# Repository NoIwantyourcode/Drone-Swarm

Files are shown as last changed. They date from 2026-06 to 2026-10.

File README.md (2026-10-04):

# Drone Swarm

This is a group of 2 drones which are autonoumously controlled by a ground controller to fly in specific patterns, the drone swarm will have 2 drones (this is expandable) and a ground controller, They ground controller will supply instructions to the drone on how to fly and where to fly, The drones will you use their Accelerometers, Gyroscopes and magnetometers to carry out these instructions and fly in a pattern.

# How does it work?

The drones are individually controlled by an onboard flight controller, Each flight controller is connected to the ESP32-S3 ground station which supplies commands to the drones for them to perform it. The ground station recieves input data on the drones location, height and distance from each other from 2 phones, one under and one below which track the the drones. this allows the ground station to have accurate locations for the drones and direct them individually!

The ground station is currently a bare ESP32-S3 DevBoard which is connected to my computer, It features nothing special but it does connect to both drones in a shared connection to supply commands to them. The commands have id's so so the both drones will not follow the same command. There is no case to increase connection strength as the connection won't be blocked by the plastic

# How is it powered

The ground station is connected to my computer and that how it recieves power, The dones have an onboard Lithium-Ion battery at 3.7v to power them for roughly 4 -5 minutes of flght time!

# Why I made this?

I made this as it links to my passion in aviation and I think it is a great way to get started with autonomous flight!

# Connection diagram!

Blank diagram

1. Dotted lines represent Non-physical connections (Bluetooth, wifi, ESP-NOW)
2. Solid lines represent physical connections (cables)

# Schematics


# PCB


# PCB rendered



# Drone frame


# Assembled view


# Fully assembled picture


# Demo link!

Heres the link to a demo video: [https://youtube.com/shorts/X6EJljXOPJc?feature=share](https://youtube.com/shorts/X6EJljXOPJc?feature=share)

# Note for reviewer
The PCB in my assembled view doesn't contain any 3D files for the components as freeCAD would not let me export the components it gathered from my raw PCB file.
The board is also 4 layers and has components on both sides

Lapse also wasn't working for a big part of the design so I wasn't really a record a ton. I only got the first ~1h20mins

Using JLCPCB to 3D print my drone frame as it is in ABS, If I can't use JLC3DP I'll try to find someone through printing legion

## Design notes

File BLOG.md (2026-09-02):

# Blog

# What went wrong?

On my way back from outpost, My baggage was mishandled causing damage to my drone rendering it in an unoperable condition, I sadly do not have pictures of said drone but I was able to fix the drone and get it back to a semi working state, however due to me being stupid, I ordered the wrong motors which weren't powerful enough at 3.7v and outputted 18,000rpm less, This is my mistake as I ordered the wrong the motors and this led to the drone not being powerful enough to lift off, while I have ordered new motors to see if I can get the drone to fly. I don't think I will get them by Sept 30th and even if I do, I won't be able to make the drone in time

# What can I do to fix it?

I used my grant to order new motors which are more efficient and output a higher power at 3.7v and am waiting for them, However I don't think they will arrive on time and even if they do I won't be able to get the drone to work on time so I will be submitting the drone for review now with some previews videos of the drone flying

# What can I do to prevent it from happening again?

When ordering repair parts, double check the specification of the motors you are buying and don't buy any which don't meet the specification or don't have a specification at all

# Current picture of the drone with the wrong motors:


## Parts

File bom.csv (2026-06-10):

Slave Drone |  | Total Price: ~196 | 210
Component | Value | Product link | Qty | Total Price ($) | Notes
Capacitor | 1uF | https://jlcpcb.com/partdetail/53938-CL05A105KA5NQNC/C52923 | 20 | 0.106
Capacitor | 10uF | https://jlcpcb.com/partdetail/20411-CL10A106KP8NNNC/C19702 | 40 | 0.592
Diode | SS14 | https://jlcpcb.com/partdetail/MDD_Microdiode_Semiconductor-SS14/C2480 | 18 | 0.3024
Diode | MBRA340 | https://jlcpcb.com/partdetail/FUXINSEMI-MBRA340T3GFS/C5563736 | 10 | 0.796
USB-C | USB_C_Receptacle_USB2.0_16P | https://jlcpcb.com/partdetail/HCTL-HC_TYPE_C_16P01A/C2894897 | 2 | 0.1972
MOSFET | SI2302-TP | https://jlcpcb.com/partdetail/79111-SI2302TP/C77977 | 12 | 0.5268
Resistor | 10K | https://jlcpcb.com/partdetail/26487-0402WGF1002TCE/C25744 | 24 | 0.0312
Resistor | 4.7K | https://jlcpcb.com/partdetail/26643-0402WGF4701TCE/C25900 | 20 | 0.02
Resistor | 100 | https://jlcpcb.com/partdetail/25819-0402WGF1000TCE/C25076 | 20 | 0.02
Resistor | 20K | https://jlcpcb.com/partdetail/26508-0402WGF2002TCE/C25765 | 20 | 0.02
Resistor | 5.1K | https://jlcpcb.com/partdetail/26648-0402WGF5101TCE/C25905 | 20 | 0.018
IMU | MPU6500 | https://jlcpcb.com/partdetail/TDKInvenSense-MPU6500/C50278 | 2 | 9.0042
ESP32-S3 | ESP32-S3-MINI-1 | https://jlcpcb.com/partdetail/EspressifSystems-ESP32_S3_MINI_1N8/C2913206 | 2 | 9.3612
Voltage Regulator | AP2112K-3.3 | https://jlcpcb.com/partdetail/TECHPUBLIC-AP2112K_33TRG1/C23380830 | 5 | 0.542
Magnetometer | QMC5883P | https://jlcpcb.com/partdetail/QST-QMC5883P/C2847467 | 2 | 3.05 | Changed to P instead of L due to part shortages || Board changed || Same footprint
1x02 pin header | Conn_01x02 | https://www.lcsc.com/product-detail/C42431804.html?s_z=n_q_l_1x02 | 1 | 0.45 | Self assembled || Comes in 20 pins
SMD Push button | SW_Push | https://jlcpcb.com/partdetail/ALPSALPINE-SKRKAHE020/C202388 | 2 | 0.87
CW Motor |  | https://www.aliexpress.com/item/1005006132824490.html?curPageLogUid=64V8cZ9sQfzZ | 4 | 8.13
CCW Motor |  | https://www.aliexpress.com/item/1005006132824490.html?curPageLogUid=64V8cZ9sQfzZ | 4 | 8.24
Propellers |  | https://www.aliexpress.com/item/1005010272672023.html?curPageLogUid=zWIs6ZE8swP7 | 2 | 5
Battery |  | https://www.aliexpress.com/item/1005008217717191.html?curPageLogUid=63gMUGmoaHrD | 2 | 10
Drone Frame |  | https://jlc3dp.com/?spm=Jlc3dp.Homepage.1001 | 2 | 11 | To be printed in ABS-ESD, strong and durable, printed by JLC3DP and will be bundled with the PCB to save money for shipping if possible
 |  |  | Total Parts price | 42.277
 |  |  | Total Price (PCBA fees incl) | 165.58
 |  |  | Total pric with shipping | 184.13
Ground Station
Component | Value | Product link | Qty | Total Price ($) | Notes
ESP32-S3 |  | https://www.aliexpress.com/item/1005011858962686.html?src=google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 | 1 | 12.5 | Communicates to all the drones simoultaneously
3D print case |  |  |  | 0
 |  |  | Total Price of all components: | ~210

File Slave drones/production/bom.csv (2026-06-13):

Designator | Footprint | Quantity | Value | LCSC Part #
C1 | 0402 | 1 | 1uF
C2, C3 | 0603 | 2 | 10uF
D1, D2, D3, D4 | D_SMA | 4 | SS14
D5, D6 | D_SMA | 2 | MBRA340
J1, J2, J3, J4, J6 | PinHeader_1x02_P2.54mm_Vertical | 5 | Conn_01x02
J5 | USB_C_Receptacle_HCTL_HC-TYPE-C-16P-01A | 1 | USB_C_Receptacle_USB2.0_16P
MOSFET1, MOSFET2, MOSFET3, MOSFET4 | SOT-23_MCC | 4 | SI2302-TP
R1, R14, R2, R3, R4, R7, R8 | 0402 | 7 | 10K
R10, R11, R12, R9 | 0402 | 4 | 100
R13 | 0402 | 1 | 20K
R16, R17 | 0402 | 2 | 5.1K
R5, R6 | 0402 | 2 | 4.7K
SW1, SW2 | SW_Push_SPST_NO_Alps_SKRK | 2 | SW_Push
U1 | InvenSense_QFN-24_3x3mm_P0.4mm | 1 | MPU6500 | C50278
U2 | QMC5883L_QST | 1 | QMC5883L | C976032
U3 | XCVR_ESP32-S3-MINI-1-N8 | 1 | ESP32-S3-MINI-1
U4 | SOT-23-5 | 1 | AP2112K-3.3

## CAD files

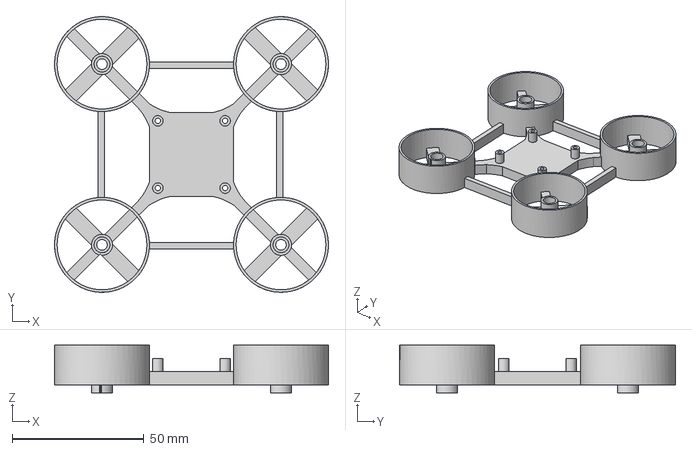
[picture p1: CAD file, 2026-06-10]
Slave drones/Drone frame/drone case.step
103.8 x 104.5 x 18.0 mm

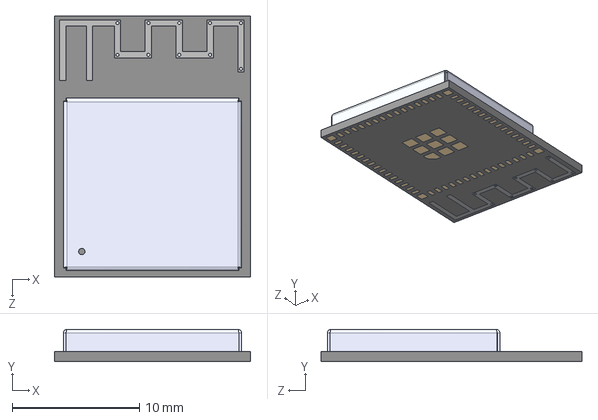
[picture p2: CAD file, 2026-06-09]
Slave drones/ESP32-S3-MINI-1-N8/ESP32-S3-MINI-1-N8.step
15.4 x 2.55 x 20.5 mm

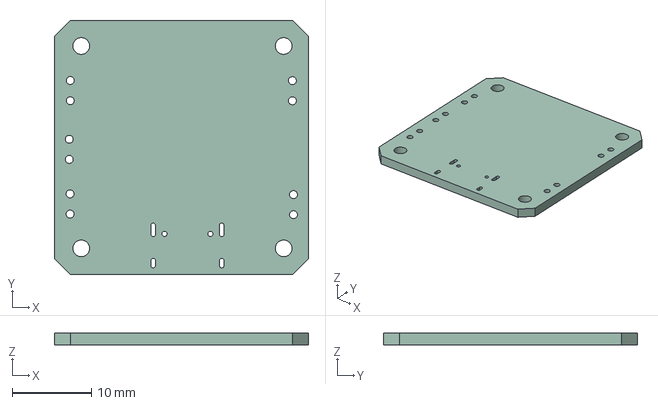
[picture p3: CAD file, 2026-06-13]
Slave drones/pcbmodel.step
32.0 x 32.0 x 1.51 mm

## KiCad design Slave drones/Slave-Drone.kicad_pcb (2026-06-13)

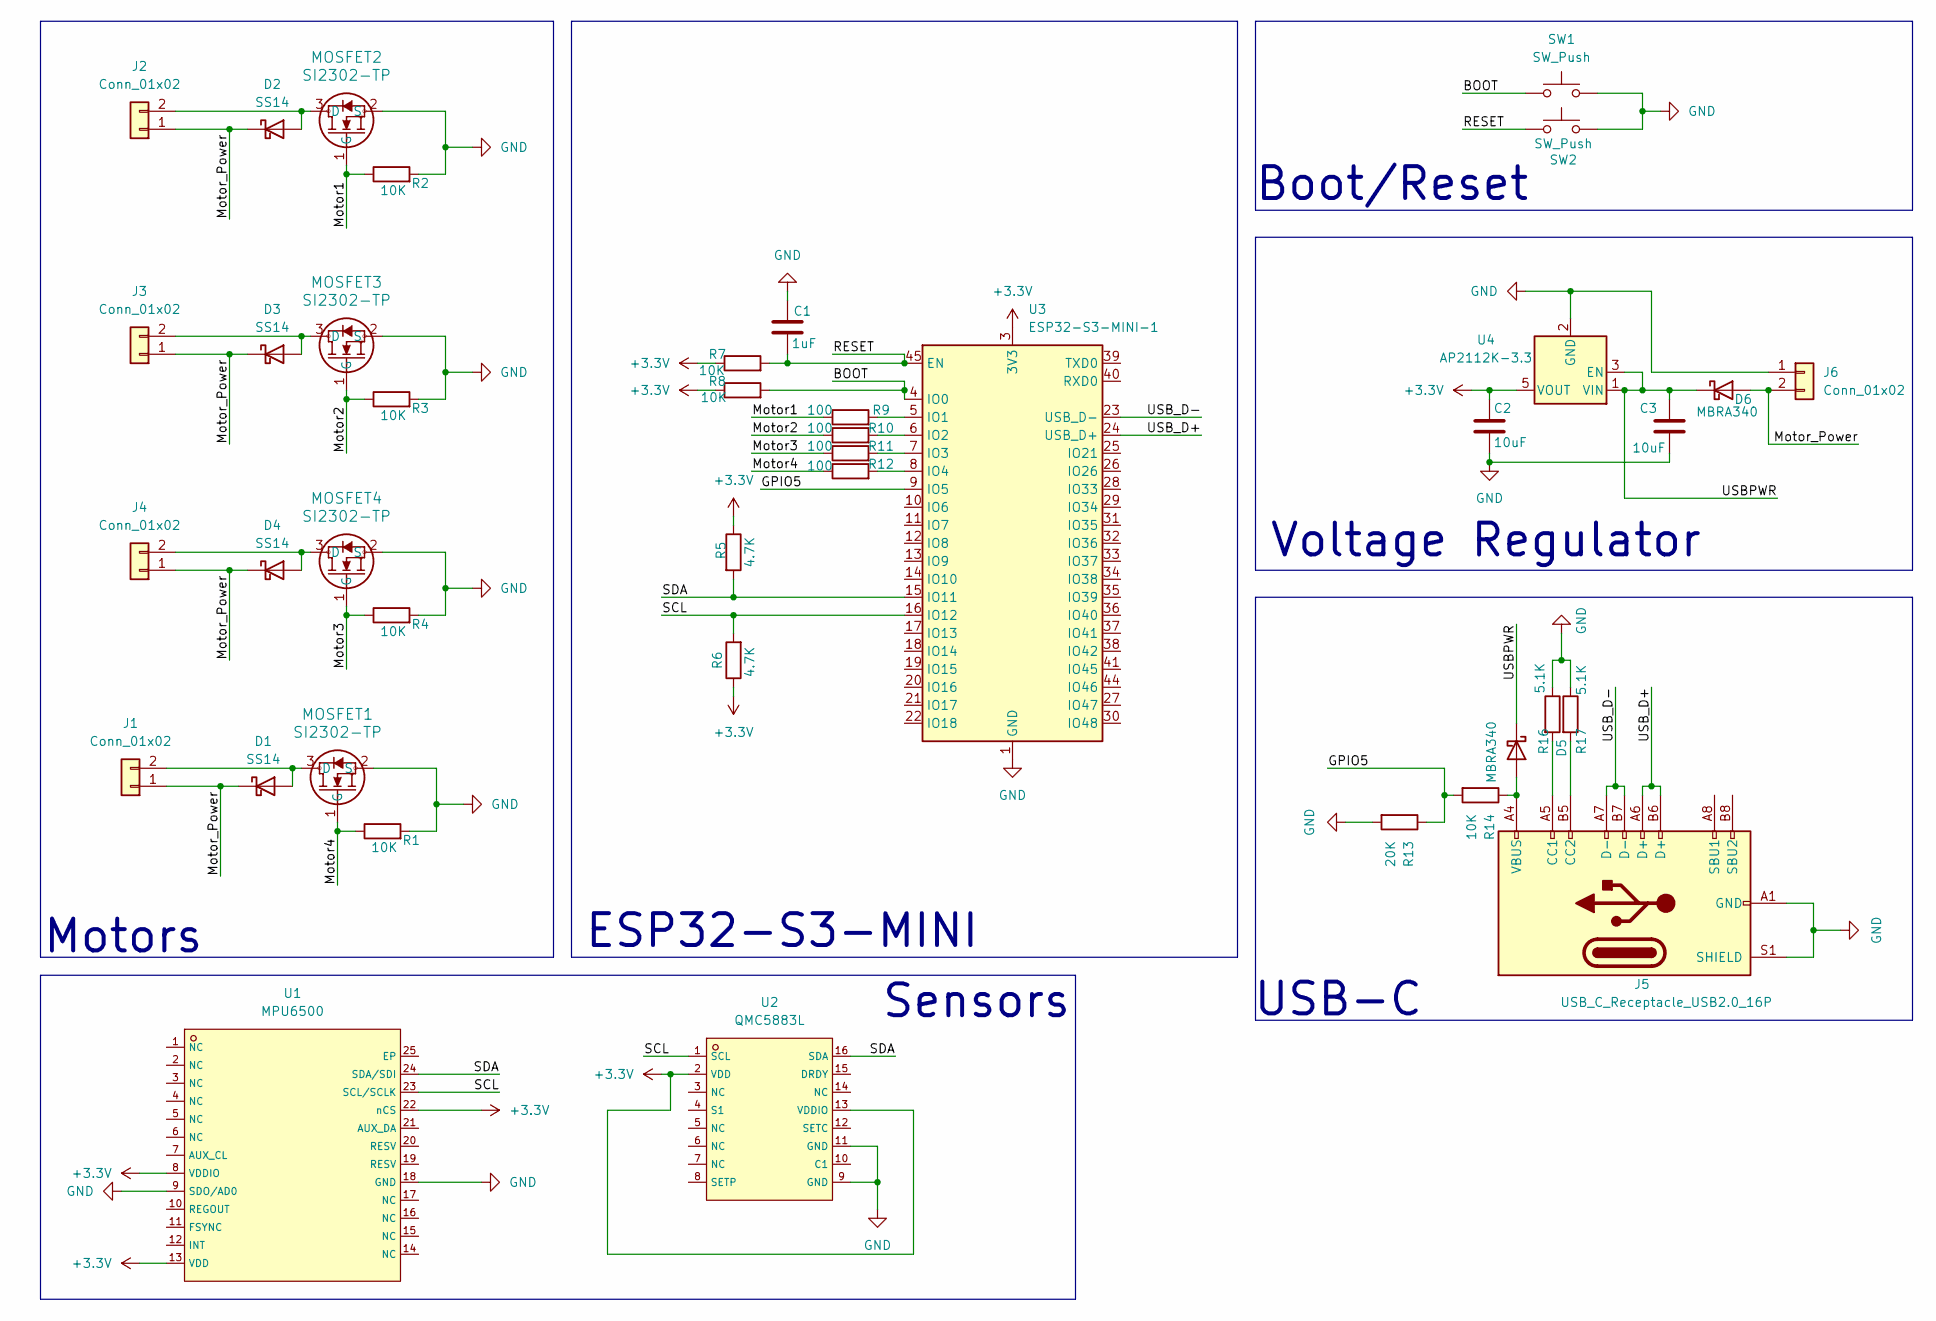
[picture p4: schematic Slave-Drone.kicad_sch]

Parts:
C1: 1uF; C_0402_1005Metric
C2, C3: 10uF; C_0603_1608Metric
D1, D2, D3, D4: SS14; D_SMA
D5, D6: MBRA340; D_SMA
J1, J2, J3, J4, J6: Conn_01x02; PinHeader_1x02_P2.54mm_Vertical
J5: USB_C_Receptacle_USB2.0_16P; USB_C_Receptacle_HCTL_HC-TYPE-C-16P-01A
MOSFET1, MOSFET2, MOSFET3, MOSFET4: SI2302-TP; SOT-23_MCC
R1, R2, R3, R4, R7, R8: 10K; R_0402_1005Metric
R5, R6: 4.7K; R_0402_1005Metric
R9, R10, R11, R12: 100; R_0402_1005Metric
R13: 20K; R_0402_1005Metric_Pad0.72x0.64mm_HandSolder
R14: 10K; R_0402_1005Metric_Pad0.72x0.64mm_HandSolder
R16, R17: 5.1K; R_0402_1005Metric
SW1, SW2: SW_Push; SW_Push_SPST_NO_Alps_SKRK
U1: MPU6500; InvenSense_QFN-24_3x3mm_P0.4mm; LCSC C50278
U2: QMC5883L; QMC5883L_QST; LCSC C976032
U3: ESP32-S3-MINI-1; XCVR_ESP32-S3-MINI-1-N8
U4: AP2112K-3.3; SOT-23-5

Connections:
+3.3V: C2.1, R5.1, R6.1, R7.1, R8.1, U1.8 (VDDIO), U1.13 (VDD), U1.22 (nCS), U2.2 (VDD), U2.13 (VDDIO), U3.3 (3V3), U4.5 (VOUT)
/BOOT: R8.2, SW1.1, U3.4 (IO0)
/GPIO5: R13.1, R14.2, U3.9 (IO5)
/Motor1: MOSFET2.1 (G), R2.1, R9.1
/Motor2: MOSFET3.1 (G), R3.1, R10.1
/Motor3: MOSFET4.1 (G), R4.1, R11.1
/Motor4: MOSFET1.1 (G), R1.1, R12.1
/Motor_Power: D1.1 (K), D2.1 (K), D3.1 (K), D4.1 (K), D6.2 (A), J1.1, J2.1, J3.1, J4.1, J6.2
/RESET: C1.2, R7.2, SW2.1, U3.45 (EN)
/SCL: R6.2, U1.23 (SCL/SCLK), U2.1 (SCL), U3.16 (IO12)
/SDA: R5.2, U1.24 (SDA/SDI), U2.16 (SDA), U3.15 (IO11)
/USBPWR: C3.1, D5.1 (K), D6.1 (K), U4.1 (VIN), U4.3 (EN)
/USB_D+: J5.A6 (D+), J5.B6 (D+), U3.24 (USB_D+)
/USB_D-: J5.A7 (D-), J5.B7 (D-), U3.23 (USB_D-)
GND: C1.1, C2.2, C3.2, J5.A1 (GND), J5.A12 (GND), J5.B1 (GND), J5.B12 (GND), J5.S1 (SHIELD), J6.1, MOSFET1.2 (S), MOSFET2.2 (S), MOSFET3.2 (S), MOSFET4.2 (S), R1.2, R2.2, R3.2, R4.2, R13.2, R16.1, R17.1, SW1.2, SW2.2, U1.9 (SDO/AD0), U1.18 (GND), U2.9 (GND), U2.11 (GND), U3.1 (GND), U3.2 (GND), U3.42 (GND), U3.43 (GND), U3.46 (GND), U3.47 (GND), U3.48 (GND), U3.49 (GND), U3.50 (GND), U3.51 (GND), U3.52 (GND), U3.53 (GND), U3.54 (GND), U3.55 (GND), U3.56 (GND), U3.57 (GND), U3.58 (GND), U3.59 (GND), U3.60 (GND), U3.61 (GND), U3.62 (GND), U3.63 (GND), U3.64 (GND), U3.65 (GND), U4.2 (GND)
unnamed: D1.2 (A), J1.2, MOSFET1.3 (D)
unnamed: D2.2 (A), J2.2, MOSFET2.3 (D)
unnamed: D3.2 (A), J3.2, MOSFET3.3 (D)
unnamed: D4.2 (A), J4.2, MOSFET4.3 (D)
unnamed: D5.2 (A), J5.A4 (VBUS), J5.A9 (VBUS), J5.B4 (VBUS), J5.B9 (VBUS), R14.1
unnamed: J5.A5 (CC1), R16.2
unnamed: J5.B5 (CC2), R17.2
unnamed: R9.2, U3.5 (IO1)
unnamed: R10.2, U3.6 (IO2)
unnamed: R11.2, U3.7 (IO3)
unnamed: R12.2, U3.8 (IO4)

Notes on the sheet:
USB-C
ESP32-S3-MINI
Voltage Regulator
Sensors
Motors
Boot/Reset

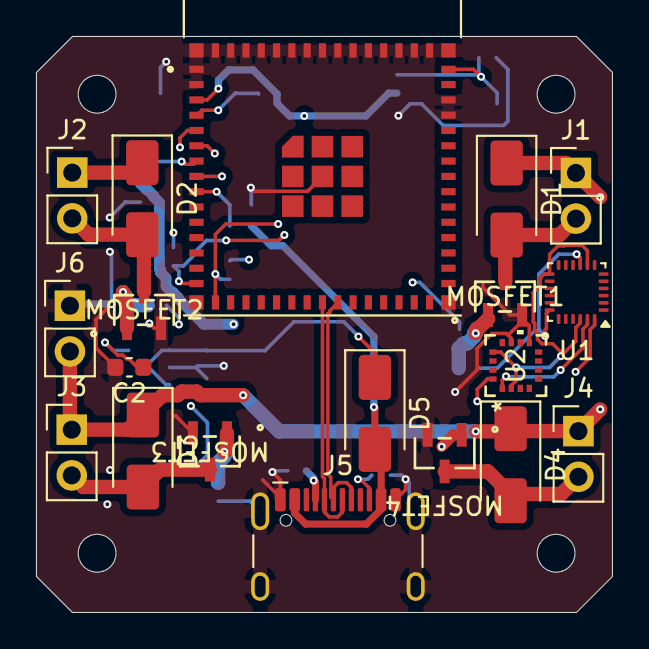
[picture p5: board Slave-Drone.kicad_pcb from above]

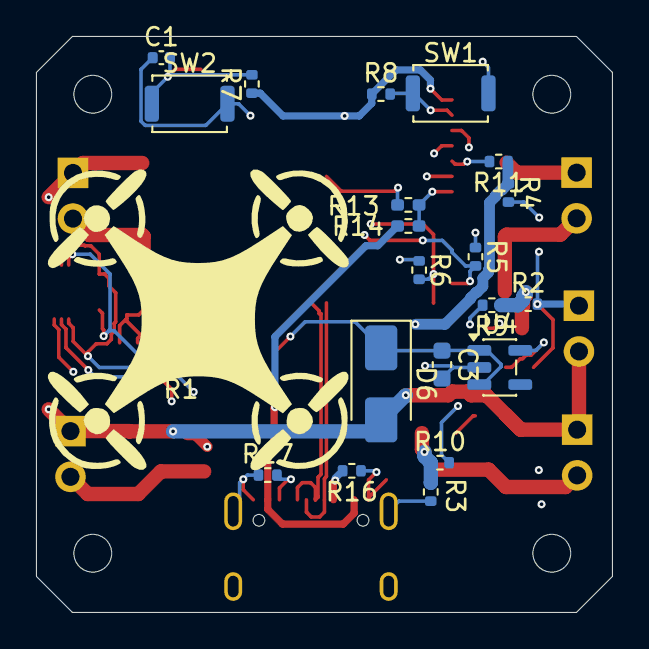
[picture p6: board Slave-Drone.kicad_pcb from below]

Board: 4 copper layers, 32.0 x 32.0 mm, 45 parts (26 on the bottom side), 26 nets.

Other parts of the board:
M1, M2, M3, M4: MountingHole_2.1mm

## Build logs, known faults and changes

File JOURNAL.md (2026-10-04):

**Total time: 70.5 hours**

# June 7th 2026 - I completed the schematics: 3 hours

I completed the schematics for the slave drones which will be controlled by the Ground station, I have decided to use an ESP32 as it is easy to use and already boasts powerful wifi/bluetooth, I have also added 2 sensors, the QMC5883P which is a magnetometer will help the drone saty aligned and the MPU6500 is an Accelerometer + Gyroscope IMU which will help the drone sense its position, I plan to use these to make the drones fly in simple patterns

Picture:


# June 7th 2026 - Routed the PCB: 3 hours

I completely routed the PCB to fit in a board 32mm by 32mm, This will allow it to fit into many widely availible whoop drone frames, The 2mm screw holes are also placed in a 25.5mm by 25.5mm grid which will allow them to screw into any existing whoop drone frame, I have also placed components on both sides of the PCB as it allows me to make it small and light which is very important in order for me be able to fly these drones without having to deal with legal issues.

Picture:


# June 8th 2026 - Made the case - 2 hours

I made the PCB case today as I realised that with the way I mounted the ESP32 I wouldn't be able to mount it at a 45 degree angle, here is a pciture of the case, It has a main 32mmx32mm platform for the flight controller and then 4 arms + propeller guards for the motors

Pictures:



# June 9th 2026 - Fixing the PCB + firmware - 3.5 hours

When I tried to export the board as step file, KiCAD gave me the error code 3, failed to load board, I went down a massive rabbit whole of trying fix it where I thought that something was off with my footprints, when I didn't find anything there I checked to see it the 3D viewer still works and it did, I tried various combinations to get the thing to work but they all failed eventually I even attempted to re-route the whole board but failed as it gave me the same error (even though I made a new file). I also deleted and reinstalled KiCAD thinking that was the problem but that didn't work either, In the end I ended up getting the step file by using an extension to get it into FreeCAD and then exporting the board out of freeCAD, However, I wasn't able to retain any components.
I also made the firmware today for both the drones however it is an early version and will need to be tweaked later on

Pictues of the board from FreeCAD, It wouldn't let me export components for some reason:


# NOTE: FROM THIS POINT ONWARDS ALL MY JOURNALS MAY NOT BE THE MOST ACCURATE AS I AM RECALLING FROM MEMORY, HOWEVER I DID WORK ON SAID PROJECT NEARLY EVERYDAY - HENCE I WILL BE JOURNALLING IN 10 - 11 DAY INCREMENTS, I WAS NOT ABLE TO TAKE MANY PICTURES BECAUSE I WAS TOO BUSY TRYING TO MAKE THE DRONE WORK

# June 19th - June 29th - 20 HOURS - Tested FCU

This week I tested my drone FCU to see if all the sensors work and tuned the software to work with the MPU while I wait for the rest of my parts to arrive.
I ended up with code which could accurately read my Gyro, Accelerometer and magnetometer

# June 29 - July 9th - 22 Hours - Assembled and made the drone work

This week I recieved all my parts and started to fully assemble the drone, along the way I realised that my drone frame was a little too heavy and I wasn't able to make the drone work, After I went back and changed the drone frame to be lighter and 3D printed it on my 3D printer I was very delighted that my drones worked!

here is an image of my drones new frame:


However, sadly after assembling the 2nd drone which would fly, while testing it I forgot to turn off my ceiling fan and it flew into it, it was broken into pieces


# July 21st to July 31st - 10 hours - Drone broken once again!

So, When I was coming back from outpost + open sauce, American baggage handling kinda slammed my suitcase super hard and broke the drone inside out of it which was the only one that was working, after coming back I ordered some spare parts and attempted to fix my drone however it didn't work I tried my best to see if I could even get it to fly but it was to no avail

heres an image of my broken drone

# note that this image has been reused

# August 1st to August 10th - 15 hours - Different software

I tried different software like Betaflight and ESP-Drone but even they didn't work as well, I am trying my best and will take everything I learnt from this to design my own firmware

Once I tried to integrate my findings into my own software, I think that the problem may be with my repair parts as the drone was not powerful enough:

But for now I am pretty tired so I will be taking a short break before I try to make my drone work once again

# August 18th to 28th - 2 hours - New spare parts

I refined my software a little more to integrate failsafes while I wait for more spare parts to arrive, I changed the motor back to the original models as I found that the ones I currently have are very inefficient and not powerful enough

These are the spare parts I ordered:


# September 20th - 5 hours

I finally got the drone to work by swapping in the motors for a new pair, the problem were the motors all along as they were far too inefficient and did not deliver enough power.
here is a picture of the drone with the swapped out motors:
drone

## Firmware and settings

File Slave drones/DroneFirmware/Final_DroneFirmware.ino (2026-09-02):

#include <Wire.h>
#include <MPU6050_light.h>
#include <esp_now.h>
#include <WiFi.h>

MPU6050 mpu(Wire);

const int M0 = 3; // Motor 0 (Front Right / CCW usually)
const int M1 = 2; // Motor 1 (Front Left / CW usually)
const int M2 = 1; // Motor 2 (Back Right / CW usually)
const int M3 = 4; // Motor 3 (Back Left / CCW usually)

// ESP-NOW Data Structure
typedef struct struct_message {
  int16_t throttle;
} struct_message;

struct_message receivedData;
volatile int16_t currentThrottle = 0;

// ---------------------------------------------------------
// PID TUNING VARIABLES
// ---------------------------------------------------------
float kp = 1.2;
float ki = 0.0;
float kd = 0.4;

float rollError, rollIntegral, prevRollError;
float pitchError, pitchIntegral, prevPitchError;
unsigned long prevTime;

// ESP-NOW Receive Callback
void OnDataRecv(const esp_now_recv_info_t *info, const uint8_t *incomingData, int len) {
  memcpy(&receivedData, incomingData, sizeof(receivedData));
  currentThrottle = receivedData.throttle;
}

void setup() {
  Serial.begin(115200);
  delay(4000);
  Serial.println("\n========================================");
  Serial.println("[SYSTEM] ESP32-S3 Flight Controller Booting...");
  Serial.print("[SYSTEM] DRONE MAC ADDRESS: ");
  Serial.println(WiFi.macAddress());
  Serial.println("========================================\n");

  // Initialize Custom I2C Pins
  Wire.begin(11, 12);
  byte status = mpu.begin();
  Serial.print("[IMU] MPU6050 status: ");
  Serial.println(status);
  
  // Keep the drone perfectly still during boot for 3 seconds!
  Serial.println("[IMU] Calculating offsets, DO NOT MOVE DRONE!");
  delay(1000);
  mpu.calcOffsets(); 
  Serial.println("[IMU] Calibration Complete.");

  ledcAttach(M0, 5000, 10);
  ledcAttach(M1, 5000, 10);
  ledcAttach(M2, 5000, 10);
  ledcAttach(M3, 5000, 10);
  
  ledcWrite(M0, 0); ledcWrite(M1, 0); ledcWrite(M2, 0); ledcWrite(M3, 0);

  if (esp_now_init() == ESP_OK) {
    Serial.println("[ESP-NOW] Initialized Successfully.");
    esp_now_register_recv_cb(OnDataRecv);
  } else {
    Serial.println("[ESP-NOW] Initialization FAILED!");
  }

  prevTime = millis();
  Serial.println("[SYSTEM] Ready for Flight Loop.");
}

void loop() {
  mpu.update();

  // Calculate loop time (dt)
  unsigned long currentTime = millis();
  float dt = (currentTime - prevTime) / 1000.0;
  prevTime = currentTime;

  if (dt <= 0) return;

  float actualRoll = mpu.getAngleY();
  float actualPitch = -mpu.getAngleX(); 

  rollError = 0 - actualRoll;
  rollIntegral += rollError * dt;
  float rollDerivative = (rollError - prevRollError) / dt;
  float rollPID = (kp * rollError) + (ki * rollIntegral) + (kd * rollDerivative);
  prevRollError = rollError;

  pitchError = 0 - actualPitch;
  pitchIntegral += pitchError * dt;
  float pitchDerivative = (pitchError - prevPitchError) / dt;
  float pitchPID = (kp * pitchError) + (ki * pitchIntegral) + (kd * pitchDerivative);
  prevPitchError = pitchError;

  int m0_val = currentThrottle + pitchPID + rollPID;
  int m1_val = currentThrottle - pitchPID + rollPID;
  int m2_val = currentThrottle + pitchPID - rollPID;
  int m3_val = currentThrottle - pitchPID - rollPID;

  if (currentThrottle < 20) {
    ledcWrite(M0, 0); 
    ledcWrite(M1, 0); 
    ledcWrite(M2, 0); 
    ledcWrite(M3, 0);

    rollIntegral = 0; 
    pitchIntegral = 0; 
  } else {
    ledcWrite(M0, constrain(m0_val, 0, 1023));
    ledcWrite(M1, constrain(m1_val, 0, 1023));
    ledcWrite(M2, constrain(m2_val, 0, 1023));
    ledcWrite(M3, constrain(m3_val, 0, 1023));
  }
}

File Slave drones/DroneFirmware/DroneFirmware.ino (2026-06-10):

#include <SPI.h>
#include <nRF24L01.h>
#include <RF24.h>
#include <Wire.h>
#include <MPU6050_tockn.h>
#include <QMC5883LCompass.h>

const int MOTOR_PIN = 4;      
const int CE_PIN = 9;         
const int CSN_PIN = 10;       

RF24 radio(CE_PIN, CSN_PIN);
const byte address[6] = "00001"; 

MPU6050 mpu6050(Wire);
QMC5883LCompass compass;

struct PacketData {
  byte throttle; 
  bool armSwitch; 
  int droneX;     
  int droneY;     
  int droneZ;     
};
PacketData radioData;

unsigned long lastSignalTime = 0;
const unsigned long TIMEOUT_MS = 500; 
bool isArmed = false;

// --- PID Altitude Parameters ---
float Kp = 1.2;  
float Ki = 0.05; 
float Kd = 0.4;  

float error = 0, lastError = 0, integral = 0, derivative = 0;
unsigned long lastLoopTime = 0;

void setup() {
  Serial.begin(115200);
  
  pinMode(MOTOR_PIN, OUTPUT);
  analogWrite(MOTOR_PIN, 0); 

  Wire.begin();
  
  // Initialize IMU
  mpu6050.begin();
  Serial.println("Calibrating IMU... Keep drone perfectly flat and still!");
  mpu6050.calcGyroOffsets(true); 

  // Initialize QMC5883P Magnetometer
  compass.init();
  // Optional: If your heading numbers feel distorted later, 
  // you will need to run the library's calibration sketch and insert your values here:
  // compass.setCalibration(minX, maxX, minY, maxY, minZ, maxZ);

  // Initialize Radio
  if (!radio.begin()) {
    while (1); 
  }
  radio.openReadingPipe(0, address);
  radio.setPALevel(RF24_PA_LOW); 
  radio.startListening();        
  
  lastLoopTime = millis();
}

void loop() {
  unsigned long currentTime = millis();
  float dt = (currentTime - lastLoopTime) / 1000.0; 

  mpu6050.update();
  
  // Read Magnetometer Heading (0 to 359 degrees)
  compass.read();
  int headingDegrees = compass.getAzimuth(); 
  if (headingDegrees < 0) {
    headingDegrees += 360; // Standardize to positive degrees
  }

  float currentRoll = mpu6050.getAngleX();
  float currentPitch = mpu6050.getAngleY();

  if (radio.available()) {
    radio.read(&radioData, sizeof(PacketData));
    lastSignalTime = currentTime; 
    
    if (radioData.armSwitch && radioData.throttle < 10 && radioData.droneX != -1) {
      isArmed = true; 
    } else if (!radioData.armSwitch || radioData.droneX == -1) {
      isArmed = false; 
      integral = 0; 
    }

    if (abs(currentRoll) > 45.0 || abs(currentPitch) > 45.0) {
      isArmed = false;
      Serial.println("SAFETY CRITICAL: TILT LIMIT EXCEEDED!");
    }

    if (isArmed && dt > 0) {
      float targetHeight = map(radioData.throttle, 0, 255, 50, 400);
      error = targetHeight - radioData.droneZ;

      integral += error * dt;
      integral = constrain(integral, -50, 50); 
      derivative = (error - lastError) / dt;

      float pidOutput = (Kp * error) + (Ki * integral) + (Kd * derivative);
      float hoverThrust = 100; 
      int finalMotorPWM = constrain(hoverThrust + pidOutput, 0, 255);

      analogWrite(MOTOR_PIN, finalMotorPWM);
      
      lastError = error;
      lastLoopTime = currentTime;

      Serial.print("Z: "); Serial.print(radioData.droneZ);
      Serial.print(" | Roll: "); Serial.print(currentRoll);
      Serial.print(" | Yaw (QMC): "); Serial.println(headingDegrees);
    } else {
      analogWrite(MOTOR_PIN, 0);
    }
  }

  if (millis() - lastSignalTime > TIMEOUT_MS) {
    isArmed = false;
    analogWrite(MOTOR_PIN, 0);
  }
}

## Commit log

2026-06-07 Completed Schematics for Drone Slave
    [Slave-Drone.kicad_pcb, Slave-Drone.kicad_sch]
2026-06-07 Completely routed the PCB
    [Slave-Drone.kicad_pcb, Slave-Drone.kicad_sch, bom.csv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]
2026-06-07 added silkscreen art
    [designators.csv]
2026-06-07 silkscreen art
    [Slave-Drone.kicad_pcb]
2026-06-07 shifted sensors to the front
    [positions.csv]
2026-06-08 changed QMC5338L to QMC5338P
    Has the same symbol/footprint but slightly different wiring
    [Slave-Drone.kicad_pcb, Slave-Drone.kicad_sch, positions.csv]
2026-06-08 Added bom
    [bom-JLCPCB Assembly Order.xls, bom.csv]
2026-06-09 tried to fix PCB
2026-06-09 I broke the pcb file, had to restart routing
    [Slave-Drone.kicad_pcb, pcbmodel.step]
2026-06-09 tried fixing error 3 - failed - use work around
    [ESP32-S3-MINI-1-N8.step, Slave-Drone.kicad_pcb, Slave-Drone.kicad_sch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]
2026-06-09 corrected mosfet placement
    [Slave-Drone.kicad_pcb, Slave-Drone.kicad_sch, bom.csv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]
2026-06-09 Added firmware
    [Slave-Drone.kicad_pcb]
2026-06-09 updated bom.csv
    [bom.csv]
2026-06-09 Updated BOM and added case files
    [Drone frame.step, bom.csv]
2026-06-10 added standoffs for drone case and updated BOM
    [Drone Frame.step, Drone frame.step, bom.csv]
2026-06-10 added PID control, allows the drone to fly
2026-06-10 update images for drone case
    Updated images for drone frame and assembled view in README.
2026-06-10 added additional support arms
    [Drone Frame.step, drone case.step]
2026-06-11 removed any vias that were on pads
    [Slave-Drone.kicad_pcb, bom.csv, designators.csv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]
2026-06-11 removed all vias on pads
    [designators.csv]
2026-06-12 Updated via hole size
    [Slave-Drone.kicad_pcb]
2026-06-13 updated QMC5883P/MPU6500/ESP32 footprints
    [Slave-Drone.kicad_pcb, Slave-Drone.kicad_sch, bom.csv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]
2026-09-02 Revise JOURNAL.md with time updates and drone details
    Updated journal entries with total time adjustments and additional details about drone assembly and issues encountered.
2026-09-02 Create blog entry about drone repair challenges
    Added a blog entry detailing issues with drone repair and motor specifications.
2026-10-04 Update total time and add September 20th entry
    Updated total time and added new journal entry about drone motor replacement.
